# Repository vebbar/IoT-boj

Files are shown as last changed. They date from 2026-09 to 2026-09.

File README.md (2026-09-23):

# IoT-boj – temperaturmätning i insjö

> **Status: pågående projekt.** Detta repo speglar var projektet befinner sig just nu – hårdvaruval och krav är på plats, men kod, CAD och testning är inte klara ännu. Bidrag, förslag och issues är välkomna!

## Syfte

En solcellsdriven boj som mäter vattentemperatur på flera djup i en insjö och skickar mätdata trådlöst (LoRa) till en mottagare/basstation, som i sin tur vidarebefordrar datan till en NAS/server som publicerar den på en hemsida.

## Krav och funktion i korthet

- Mäter vattentemperatur på tre djup: **-0,3 m, -1 m, -2 m**, monterade på ett 2 m långt aluminiumrör under bojen
- Skickar temperatur + batteristatus **en gång i timmen**
- Placeras i allmänt vatten → ska vara **hyfsat billig** (risk för vandalisering/stöld)
- Ute **året runt i Stockholmsområdet** → måste tåla kyla
- Höljet **3D-printas**
- Strömförsörjs via **solcell (6 V/2 A) + 2x 18650-batteri**
- Kommunicerar via **LoRa (868 MHz)**, ca 100 m genom vegetation, till en mottagare
- Kommunikation sker alltid **boj → mottagare → server** (push), aldrig tvärtom

## Arkitektur

```
[Boj: Heltec Wireless Stick Lite V3    --LoRa 868MHz-->  [Mottagare: Waveshare
 (ESP32-S3+SX1262) + 3x DS18B20]                          ESP32-S3-POE-ETH + SX1276]
                                                                    |
                                                             push data
                                                                    v
                                                          [NAS/server → hemsida]
```

Mottagaren står fast vid sjön. Servern kan flytta med användaren till andra nät – därför initieras kommunikationen alltid från mottagaren mot servern, aldrig tvärtom.

## CAD

Höljet och de mekaniska delarna designas i Onshape: se [`cad/onshape-link.md`](cad/onshape-link.md) för länk och status.

## Hårdvara (sammanfattning)

**Boj**
- Heltec Wireless Stick Lite V3 (ESP32-S3 + inbyggt LoRa SX1262), 868 MHz
- 3x DS18B20 vattentäta temperatursensorer (0,3/1/2 m djup, på aluminiumrör)
- 2x 18650 Li-ion-celler med integrerad BMU
- Solcell 6 V/2 A + laddkrets CN3065 + buck-boost-converter
- INA219 för batteritelemetri

**Mottagare**
- Waveshare ESP32-S3-POE-ETH
- extern SX1276 LoRa-modul

**Regulatoriskt:** Sändare på 868 MHz, duty cycle max 1 % i bandet 868,0–868,6 MHz (~36 sek/timme) enligt PTS.

## Kända öppna frågor / risker

- **Is** är den största risken året runt i Stockholm – inte vind/vågor. Ett betongankare löser inte problemet med isflak. Att ta upp bojen inför islägget är den säkraste lösningen.
- Exakt placering (sjönamn/koordinater) publiceras medvetet **inte** här, för att minska risken för stöld/vandalisering.

## Licens

Detta projekt är licensierat under **MIT-licensen** – se [`LICENSE`](LICENSE). Det innebär i korthet att vem som helst får använda, kopiera, ändra och dela koden/materialet, även kommersiellt, så länge ursprungligt copyright-meddelande behålls. Programvaran ges utan garantier.

## Bidra

Detta är ett pågående hobbyprojekt. Öppna gärna en issue om du har frågor eller förslag.

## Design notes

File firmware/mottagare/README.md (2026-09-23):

# IoT-Boj LoRa Mottagare

LoRa-mottagare byggd på **Waveshare ESP32-S3-POE-ETH** med extern **SX1276** LoRa-modul. Tar emot textpaket från sändarbojen (Heltec Wireless Stick Lite V3) och skriver ut dem i Serial Monitor. Loggar också till den inbyggda TF-kortläsaren.

## Hårdvara

| Komponent | Modell |
|---|---|
| Mottagare | Waveshare ESP32-S3-POE-ETH |
| LoRa-modul | SX1276 (extern, via kablage) |
| (Valfritt) | TF-kort (inbyggt på mottagar-kortet) |

## Projektbeskrivning

Denna kod körs på en Waveshare ESP32-S3-POE-ETH och tar emot textpaket från sändarbojen via en extern SX1276 LoRa-modul. Varje mottaget paket skrivs ut i Serial Monitor tillsammans med RSSI och SNR, och loggas till den inbyggda TF-kortläsaren på kortet.

LoRa-inställningarna måste matcha sändaren: 868.0 MHz, bandbredd 125 kHz, spreading factor 7, coding rate 4/5 och sync word 0x3B. Payloaden innehåller temperaturer, sensorstatus och batterivärden från bojen och behandlas i nuläget som text.

## Viktiga pin-konflikter (ESP32-S3-POE-ETH)

ESP32-S3-POE-ETH har GPIO4/5/6/7 hårdkopplade till den inbyggda TF-kortplatsen, och GPIO9/10/11/12/13/14 hårdkopplade till det inbyggda W5500 Ethernet-chippet. De pinnarna kan INTE återanvändas för den externa LoRa-modulen. Därför körs LoRa och TF-kortet nu på två separata SPI-bussar med olika pinnar, istället för att dela en buss som i den gamla ESP32-C3-versionen.

GPIO0, GPIO3, GPIO45 och GPIO46 är strapping-pinnar och undviks medvetet.

NAS-stöd är förberett men avstängt. Senare kan `USE_NAS` och `sendToNas()` byggas ut med WiFi/HTTP (eller Ethernet via W5500) så att mottagna data skickas vidare till NAS.

> **OBS – innan detta pushas till en publik server:** `NAS_URL` är just nu en privat (lokal) IP-adress och skadar inte att dela. Om ni senare pekar mot en publik adress med autentisering, lägg autentiseringsuppgifter i en `.env`/hemlighetsfil (se `.gitignore` i repo-roten), aldrig direkt i koden.

## Pinout

### LoRa (extern SX1276, egen SPI-buss "loraSPI")
| Funktion | GPIO |
|---|---|
| SCK | 18 |
| MISO | 16 |
| MOSI | 17 |
| CS | 1 |
| RESET | 15 |
| DIO0 | 2 |

### TF-kort (inbyggt på kortet, egen SPI-buss "sdSPI", FASTA pinnar)
| Funktion | GPIO |
|---|---|
| SCK | 7 |
| MISO | 5 |
| MOSI | 6 |
| CS | 4 |

### Inbyggd LED (NeoPixel, GPIO 21)
| Status | LED |
|---|---|
| Lyssnar (ingen data) | Grön puls, mycket dim |
| Fel (CRC/error) | Röd, mycket dim |
| Paket mottaget | Blå blink (1 sekund) |

LED-styrning är standard inaktiverad (`USE_LED=0` i `main.cpp`). För att aktivera: sätt `#define USE_LED 1`

### Reserverat av Ethernet (W5500) — används inte av denna kod
GPIO9 (ETH_RST), GPIO10 (ETH_INT), GPIO11 (ETH_MOSI), GPIO12 (ETH_MISO), GPIO13 (ETH_CLK), GPIO14 (ETH_CS)

GND är gemensam för alla moduler.

## LoRa-inställningar (måste matcha sändare)

| Parameter | Värde |
|---|---|
| Frekvens | 868.0 MHz |
| Bandbredd | 125 kHz |
| Spreading factor | 7 |
| Coding rate | 4/5 |
| Sync word | 0x3B |

## Bygg och ladda upp

```bash
pio run -t upload
pio device monitor
```

Serial Monitor körs på 115200 baud (inställt i `platformio.ini`).

## Status

- `USE_SD` — SD-loggning aktiverad (sätt till 0 för felsökning utan TF-kort)
- `USE_NAS` — inaktivt (för framtida WiFi/Ethernet-integrering)

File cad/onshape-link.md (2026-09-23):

# CAD – Onshape

Käll-CAD för bojens hölje och mekaniska delar hålls i Onshape. Detta är den "levande" versionen – STEP/STL-filer i `step/` och `stl/` är exporterade ögonblicksbilder och kan ligga efter.

**Onshape-dokument:**
https://cad.onshape.com/documents/031defd88e958e1781d0b804/w/505ddeea769f05b2173c275a/e/bcfe48d20ba4c53c8e3ff33c

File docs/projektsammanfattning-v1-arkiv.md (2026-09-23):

# IoT-boj – Projektsammanfattning

*Sammanställd 2026-08-14 utifrån projektunderlag och diskussion.*

## Syfte
En temperaturboj som mäter vattentemperatur på flera djup och skickar data trådlöst till en basstation.

## Krav
- Mäter vattentemperatur på minst tre nivåer: **-0,2 m, -1 m, -2 m**
- Ev. lufttemperatur
- Placeras i **allmänt vatten** → ska vara **hyfsat billig** (risk för vandalisering/stöld)
- Ligger ute **året runt i Stockholm** → måste tåla kyla
- Höljet **3D-printas** (Bambu Lab P1S)
- Strömförsörjs via **solcell** som laddar batteri
- Kommunicerar via LoRa ca **100 m** till basstationen, genom vegetation ("foliage")
- Basstation: Raspberry Pi Zero W2 (finns redan), sitter kvar vid sjön hos föräldrarna
- Server flyttar med användaren till annat nät → kommunikation sker **Pi → server (push)**, aldrig tvärtom

## Fysiska mått (boj)
- Ungefär rund
- Omkrets ca **200 mm**
- Höjd/djup ca **150 mm**
- 3D-printas på Bambu Lab P1S

## Plats/miljö
- Insjö
- Vattendjup: **3 m**
- Vindutsatt läge

## Inköpslista – elektronik/IoT

### Styrenhet & radio
- ESP32 med inbyggt LoRa (SX1262), 868 MHz — motsvarande YourCee-modulen
- 3x DS18B20 vattentät temperatursensor (för -0,2, -1, -2 m djup)

### Kraftsystem
- 2–3x 18650 Li-ion-celler, gärna "protected"
- Batterihållare för 2–3 celler (parallellkoppling)
- Solar charge controller för 18650, t.ex. CN3065-baserad modul eller Adafruit/DFRobot Solar Lipo Charger
- Solpanel, ca 5–6V, 1–2W (extra marginal rekommenderas pga Stockholms vinter)
- Spänningsregulator (buck/boost till stabil 3,3V), om inte redan inbyggd
- Ev. INA219-modul för batterispänning/laddström (telemetri, systemhälsa)

### Övrig elektronik
- Vattentät SMA-genomföring (om extern antenn behövs)
- Vattentäta kabelgenomföringar (cable glands) för sensorkablar
- Reed switch (valfritt, för strömbrytning)

### Basstation (Raspberry Pi Zero W2 – finns redan)
- SX1276/78 LoRa-modul (868 MHz) — samma typ som SZFYDOSH-modulen
- SPI-kablage/pinheader till Pi:ns GPIO
- Antenn till LoRa-modulen (ingår ofta i kit)
- microSD-kort (tillräcklig storlek/klass för SQLite-loggning)

### Noteringar
- ESP32-C3 Super Mini används **inte** i slutgiltiga projektet
- Sändarfrekvens 868 MHz, duty cycle max 1% i bandet 868,0–868,6 MHz (~36 sek/timme) enligt PTS
- Basstationen sitter fast vid sjön; servern flyttar med användaren

## Förankring – beräkning och rekommendation

**Given flytkraft:** 5 kg

### Slutsats
En **25 kg säck betong**, gjuten till en klump, räcker med god marginal.

### Motivering
- Vindyta på bojen är liten (Ø~200 mm, ~150 mm höjd) → vindkraft ca 3–5 N även vid kraftig byvind
- Ström i insjö är svag (0,1–0,3 m/s) → liten kraft på nedsänkt del
- Betong väger ca 2000–2400 kg/m³ och tappar ~45–55% av sin vikt i vatten
- 25 kg betong i luft → ca 13–14 kg nedsänkt vikt → 2,5–3x marginal mot flytkraften, plus marginal mot vind/våg/ström

### Praktiska rekommendationer
- Gjut betongen i en hink/spann, gjut in en ögla/bult för infästning
- Använd en kort kätting (0,5–1 m) närmast klumpen, sedan lina upp till bojen — ger horisontellt drag och minskar risk att ankaret lyfts
- **Scope (linlängd):** sikta på 6–9 m totalt (2–3x vattendjupet på 3 m)

### ⚠️ Viktig varning – is
Den verkliga risken året runt i Stockholm är **is**, inte vind/vågor. Ett rörligt isflak kan ge krafter som vida överstiger vad ett betongankare klarar av, och kan dra ner eller krossa bojen. Vanliga lösningar:
- Ta upp bojen inför islägg, **eller**
- Acceptera risk för förlust/skada under vintern

Betongankaret löser inte is-problematiken.

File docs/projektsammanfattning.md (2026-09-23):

# IoT-boj – Projektsammanfattning (uppdaterad)

*Senast uppdaterad 2026-09-23.*

> Denna fil ersätter tidigare version. Den äldre versionen (med djupen -0,2/-1/-2 m) finns kvar i [`projektsammanfattning-v1-arkiv.md`](projektsammanfattning-v1-arkiv.md) för historik, men uppgifterna nedan är de aktuella.

## Syfte

Ett projekt bestående av en boj som mäter vattentemperaturen i en insjö i Stockholmsområdet, samt en mottagare/basstation som vidarebefordrar datan till en NAS/server som i sin tur publicerar den på en hemsida.

## Funktion

- Bojen har tre temperatursonder på tre djup: **0,3 m, 1 m, 2 m**
- Sonderna sitter monterade på ett **2 m långt aluminiumrör** under bojen
- Bojen skickar temperaturdata **en gång i timmen**, tillsammans med batteristatus
- Data tas emot av en mottagare ca **100 m** bort
- Mottagaren skickar vidare datan till en **NAS/server**, som publicerar den på en **hemsida**

## Hårdvara – Boj

- Styrenhet/radio: **Heltec Wireless Stick Lite (V3)** – ESP32-S3 + SX1262 LoRa-nod (Meshtastic- och LoRaWAN-kompatibel)
- 2x 18650-batterier med integrerad BMU (batterihanteringskrets)
- 3x DS18B20 vattentäta temperatursensorer
- Solcell, 6 V / 2 A
- Laddkrets: CN3065
- Buck-boost-converter (spänningsreglering)
- INA219 för batteritelemetri (spänning/ström)

## Hårdvara – Mottagare

- **Waveshare ESP32-S3-POE-ETH**
- Extern **SX1276** LoRa-modul

## Krav (bakgrund, se även syfte-och-krav.md)

- Placeras i allmänt vatten → ska vara hyfsat billig (risk för vandalisering/stöld)
- Ute året runt i Stockholm → måste tåla kyla
- Höljet 3D-printas
- Solcellsladdat batteri
- LoRa 868 MHz, ca 100 m genom vegetation
- Kommunikation sker boj/mottagare → server (push), aldrig tvärtom

## Förankring – beräkning och rekommendation

**Given flytkraft:** 5 kg

### Slutsats
En **25 kg säck betong**, gjuten till en klump, räcker med god marginal.

### Motivering
- Vindyta på bojen är liten → vindkraft ca 3–5 N även vid kraftig byvind
- Ström i insjö är svag (0,1–0,3 m/s) → liten kraft på nedsänkt del
- Betong väger ca 2000–2400 kg/m³ och tappar ~45–55 % av sin vikt i vatten
- 25 kg betong i luft → ca 13–14 kg nedsänkt vikt → 2,5–3x marginal mot flytkraften

### Praktiska rekommendationer
- Gjut betongen i en hink/spann, gjut in en ögla/bult för infästning
- Kort kätting (0,5–1 m) närmast klumpen, sedan lina upp till bojen
- **Scope (linlängd):** sikta på 6–9 m totalt (2–3x vattendjupet på 3 m)

### ⚠️ Viktig varning – is
Den verkliga risken året runt i Stockholm är **is**, inte vind/vågor. Ett rörligt isflak kan ge krafter som vida överstiger vad ett betongankare klarar av. Vanliga lösningar:
- Ta upp bojen inför islägg, **eller**
- Acceptera risk för förlust/skada under vintern

Betongankaret löser inte is-problematiken.

## Noteringar

- ESP32-C3 Super Mini används **inte** i det slutgiltiga projektet
- Sändarfrekvens 868 MHz, duty cycle max 1 % i bandet 868,0–868,6 MHz (~36 sek/timme) enligt PTS
- Basstationen sitter fast vid sjön (hos föräldrarna); servern flyttar med användaren till andra nät

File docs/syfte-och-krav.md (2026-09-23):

Bojen ska mäta vattentemperaturen på minst tre nivåer -0,2, -1 och -2m. Och eventuellt lufttemperatur. Bojen kommer befinna sig i Allmänt vatten så ska vara hyfsat billigt då den lätt kan bli vandaliserad eller stulen. Bojen kommer vara ute året runt (Stockholm) så behöver tåla vis kyla. Bojen kommer att 3d printas. För att bojen ska fungera komer den behöva en solceller för att ladda upp batteriet/er. Bojen kommer befinna sig ca 100m från basstationen genom foliage.

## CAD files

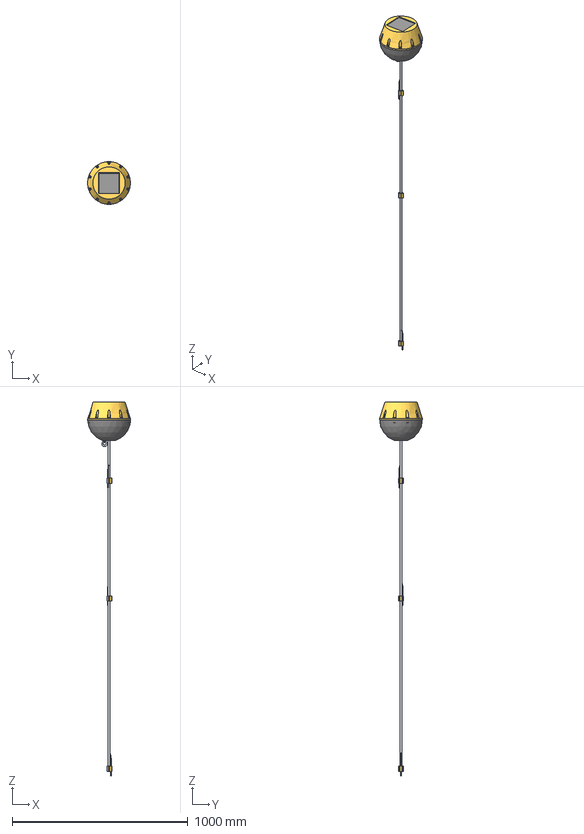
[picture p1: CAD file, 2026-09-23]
cad/IoT-boj Assembly.step
243.8 x 243.8 x 2128.9 mm
fyrkants mutter x 10
Bult x 10
boj_top
boj_base
solcell
bricka
ögla
mutter
DS18B20 clip x 3
DS18B20 x 3
aluminium stång
Solar Charger v1.0
Heltec esp32 LoRa
TPS63020 Buck Boost
Kopplingsdosa
Kopplingsdosa_lock
Kopplingsdosa pakning

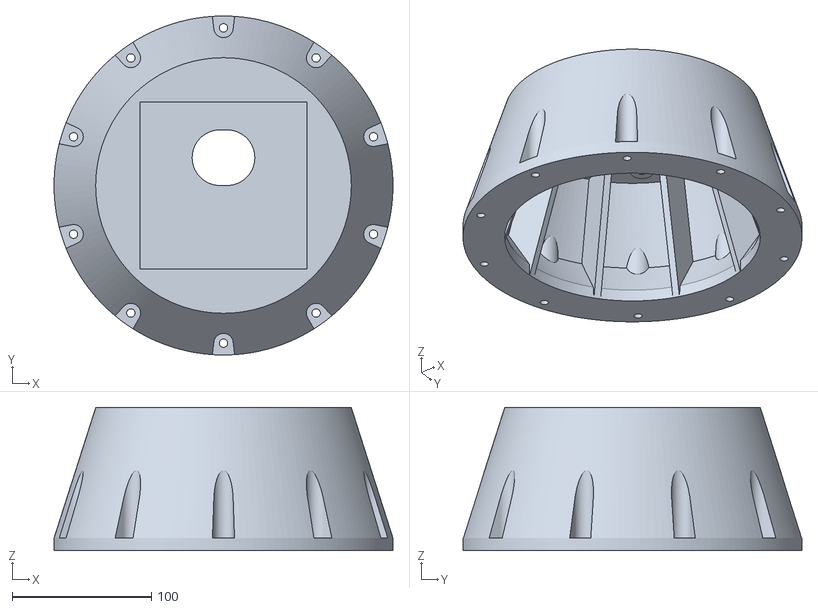
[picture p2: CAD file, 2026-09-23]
cad/Boj_Top.stl
243.8 x 243.8 x 103.0

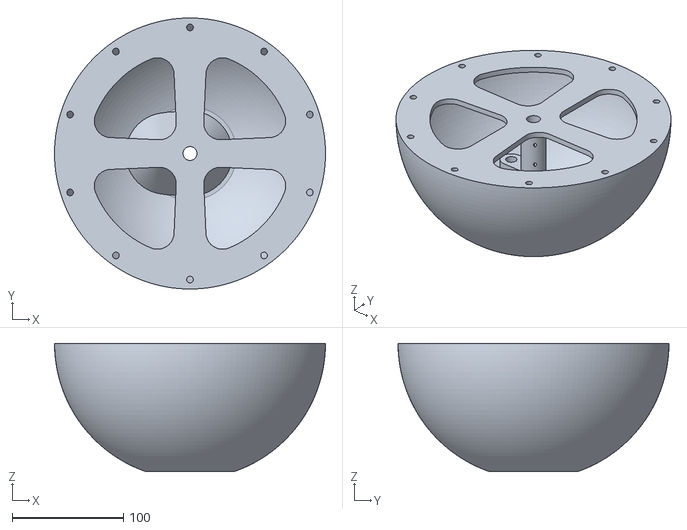
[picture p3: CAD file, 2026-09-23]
cad/Boj_Base.stl
243.8 x 243.8 x 115.2

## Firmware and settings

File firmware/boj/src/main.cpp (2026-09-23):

#define HELTEC_WIRELESS_STICK_LITE   // måste stå FÖRE include-raden nedan
#define HELTEC_NO_DISPLAY            // Stick Lite saknar skärm, slipper onödig init
#include <heltec_unofficial.h>       // skapar en färdig 'radio'-instans med rätt pinnar för just detta kort

#include <Arduino.h>
#include <OneWire.h>
#include <DallasTemperature.h>
#include <Wire.h>
#include <Adafruit_INA219.h>

// Data-sladd för DS18B20 sensorer på GPIO 15
const int ONE_WIRE_PIN = 15;
//SDA från INA219 på GPIO 2
const int SDA_PIN = 2;
//SCL från INA219 på GPIO 7
const int SCL_PIN = 7;

Adafruit_INA219 ina219;
OneWire oneWireBus(ONE_WIRE_PIN);
DallasTemperature sensors(&oneWireBus);

const int NUM_SENSORS = 3;

// Sensoradresser för DS18B20
// Sensor 1 (0.3m): 28CAFDC3000000B5
// Sensor 2 (1.0m): 28AE33C4000000AC
// Sensor 3 (2.0m): 2833C9C3000000CA
DeviceAddress sensorAddresses[NUM_SENSORS] = {
  {0x28, 0xCA, 0xFD, 0xC3, 0x00, 0x00, 0x00, 0xB5},
  {0x28, 0xAE, 0x33, 0xC4, 0x00, 0x00, 0x00, 0xAC},
  {0x28, 0x33, 0xC9, 0xC3, 0x00, 0x00, 0x00, 0xCA}
};

// Etiketter för utskrift, en per sensor/djup
const char* depthLabels[NUM_SENSORS] = {"0.3m", "1.0m", "2.0m"};

// Senaste kända bra värde per sensor (används om en mätning misslyckas) sparat i RTC minne
RTC_DATA_ATTR float lastGoodTemp[NUM_SENSORS] = {0.0, 0.0, 0.0};

bool ina219Available = false;  // global variabel, börjar som "inte tillgänglig"

// OBS: 'radio' (SX1262) skapas automatiskt av heltec_unofficial.h ovan,
// med korrekta pinnar för Wireless Stick Lite V3 - ingen egen Module()-instans behövs.

struct TemperatureResult {
  float averageTemperature;
  bool isSuccessful;
  float rawTemperature;
};

void getSafeTemperatures(TemperatureResult results[], int samples);

void setup() {
  heltec_setup();  // Initierar Serial, SPI (hspi->begin) och display (om aktiv)
  Serial.println("CHECKPOINT 1: heltec_setup() klar");

  heltec_ve(true); // Slår på Vext-strömskenan -- annars är externa sensorer (t.ex. INA219) strömlösa
  Serial.println("CHECKPOINT 2: heltec_ve(true) klar");

  delay(300);      // ge Vext-skenan gott om tid att stabiliseras innan sensorer pratas med
  Serial.println("CHECKPOINT 3: delay(300) klar");

  unsigned long serialWaitStart = millis(); //väntar på usb kontakt i 3 sekunder
  while (!Serial && millis() - serialWaitStart < 3000) {
    delay(10);
  }
  Serial.println("CHECKPOINT 4: serial-vantan klar");

  sensors.begin();
  Serial.println("CHECKPOINT 5: sensors.begin() klar");

  int deviceCount = sensors.getDeviceCount();
  Serial.println("CHECKPOINT 6: sensors.getDeviceCount() klar");
  Serial.print("DS18B20: hittade ");
  Serial.print(deviceCount);
  Serial.println(" sensorer.");
  if (deviceCount < NUM_SENSORS) {
    Serial.println("VARNING: färre sensorer hittades än förväntat!");
  }

  Wire.begin(SDA_PIN, SCL_PIN);
  Serial.println("CHECKPOINT 7: Wire.begin() klar");

  Wire.setClock(100000);  // konservativ I2C-hastighet (100kHz) för tillförlitligare läsningar
  Serial.println("CHECKPOINT 8: Wire.setClock() klar");

  // "Väck" I2C-bussen genom att snabbt pinga alla möjliga adresser en gång.
  // Detta visade sig lösa ett problem där INA219 inte svarade tillförlitligt
  // direkt efter Vext-strömpåslag - troligen på grund av hur ESP32:ans
  // I2C-drivrutin återhämtar bussen efter flera transaktioner (inklusive NACK:ar).
  for (byte addr = 1; addr < 127; addr++) {
    Wire.beginTransmission(addr);
    Wire.endTransmission();
  }
  Serial.println("CHECKPOINT 9: I2C-bus-scan klar");

  bool ina219Found = false;
  for (int attempt = 1; attempt <= 5 && !ina219Found; attempt++) {
    if (ina219.begin()) {
      ina219Found = true;
    } else {
      delay(50);
    }
  }
  Serial.println("CHECKPOINT 10: ina219.begin()-forsok klara");

  if (!ina219Found) {
    Serial.println("Kunde inte hitta INA219! Fortsätter utan batterimätning denna cykel.");
    // ina219Available förblir false, ingen while(1) här
  } else {
    ina219Available = true;
    Serial.println("INA219 hittad, startar mätning...");
  }

  // Initiera LoRa (SX1262) - 'radio' kommer från heltec_unofficial.h
  Serial.println("Initierar LoRa...");
  int state = radio.begin(868.0, 125.0, 7, 5, 0x3B, 12);
  Serial.println("CHECKPOINT 11: radio.begin() klar");
  if (state != RADIOLIB_ERR_NONE) {
    Serial.println("LoRa init misslyckades: " + String(state));
  } else {
    Serial.println("LoRa init OK.");
  }

  // Mät alla sensorer
  TemperatureResult results[NUM_SENSORS];
  getSafeTemperatures(results, 3);
  Serial.println("CHECKPOINT 12: getSafeTemperatures() klar");

  // Bygg payload (textformat)
  String payload = "";
  for (int i = 0; i < NUM_SENSORS; i++) {
    if (results[i].isSuccessful) {
      lastGoodTemp[i] = results[i].averageTemperature;
    }

    payload += "T_";
    payload += depthLabels[i];
    payload += ":";
    payload += String(lastGoodTemp[i], 1);
    payload += ",S";
    payload += String(i);
    payload += ":";
    payload += results[i].isSuccessful ? "1" : "0";

    if (i < NUM_SENSORS - 1) {
      payload += ",";
    }
  }

  if (ina219Available) {
    float voltage = ina219.getBusVoltage_V() + (ina219.getShuntVoltage_mV() / 1000);
    float current = ina219.getCurrent_mA();
    float power = ina219.getPower_mW();
    payload += ",Vbat:";
    payload += String(voltage, 2);
    payload += "V,I:";
    payload += String(current, 0);
    payload += "mA,P:";
    payload += String(power, 0);
    payload += "mW";
  } else {
    payload += ",Vbat:OFFLINE";
  }
  Serial.println("CHECKPOINT 13: payload byggd");

  // Skriv till Serial för felsökning
  Serial.println("Payload: " + payload);

  // Sänd via LoRa
  if (state == RADIOLIB_ERR_NONE) {
    Serial.println("Sänder via LoRa...");
    int txState = radio.transmit(payload);
    Serial.println("CHECKPOINT 14: radio.transmit() klar");
    if (txState != RADIOLIB_ERR_NONE) {
      Serial.println("LoRa sändning misslyckades: " + String(txState));
    } else {
      Serial.println("LoRa sändning klar.");
    }
  }

  // Gå i deep sleep i 1 timme
  Serial.println("Går i deep sleep i 1 timme...");
  heltec_ve(false);  // Stäng av Vext -- annars drar pull-up-resistorn ström i onödan under hela sömnen
  delay(100); // ge tid för Serial-att avsluta
  heltec_deep_sleep(3600);  // Sätter radio i sleep, sätter timer wakeup + esp_deep_sleep_start()
}

void loop() {
  // Tom - inget händer här efter deep sleep-setup
}

/**
 * @brief Mäter temperaturen på alla sensorer samtidigt, flera gånger,
 *        och beräknar medelvärdet av de godkända mätningarna per sensor.
 *
 * @param results Array (storlek NUM_SENSORS) dit resultaten skrivs.
 * @param samples Antal mätomgångar som ska göras.
 */
void getSafeTemperatures(TemperatureResult results[], int samples) {
  float sumOfGoodTemps[NUM_SENSORS] = {0};
  int countOfGoodTemps[NUM_SENSORS] = {0};
  float lastObservedTemp[NUM_SENSORS] = {0};

  for (int i = 0; i < samples; i++) {
    sensors.requestTemperatures();  // EN broadcast per sample, alla sensorer samtidigt

    for (int s = 0; s < NUM_SENSORS; s++) {
      float currentTemp = sensors.getTempC(sensorAddresses[s]);
      lastObservedTemp[s] = currentTemp;

      // Kontrollera om värdet är inom det godkända intervallet
      if (currentTemp > -30.0 && currentTemp < 40.0) {
        sumOfGoodTemps[s] += currentTemp;
        countOfGoodTemps[s]++;
      }
    }
  }

  for (int s = 0; s < NUM_SENSORS; s++) {
    if (countOfGoodTemps[s] > 0) {
      results[s].averageTemperature = sumOfGoodTemps[s] / countOfGoodTemps[s];
      results[s].isSuccessful = true;
      results[s].rawTemperature = lastObservedTemp[s];
    } else {
      results[s].averageTemperature = 0.0;
      results[s].isSuccessful = false;
      results[s].rawTemperature = lastObservedTemp[s];
    }
  }
}

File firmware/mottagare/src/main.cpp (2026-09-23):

// Se README.md för full dokumentation av pinout, LoRa-inställningar och LED-beteende.

#include <Arduino.h>
#include <SPI.h>
#include <RadioLib.h>

// TF-kortet sitter inbyggt på kortet, så SD-loggning är påslaget som standard.
// Sätt till 0 om du vill köra utan SD-loggning (t.ex. för felsökning).
#define USE_SD 1
// Forberedelse for framtida NAS-integration (t.ex. via Ethernet/W5500).
constexpr bool USE_NAS = false;
constexpr char NAS_URL[] = "http://192.168.1.100:8086/api/v1/temps";

// ---------- LoRa (extern SX1276-modul, egen SPI-buss) ----------
// OBS! GPIO21 är enligt schemat (R15, 0R) hårdkopplad till den inbyggda WS2812
// RGB-lysdioden. LORA_CS flyttad hit ifrån för att slippa krocka med den.
constexpr int LORA_SCK   = 18;
constexpr int LORA_MISO  = 16;
constexpr int LORA_MOSI  = 17;
constexpr int LORA_CS    = 1;
constexpr int LORA_RESET = 15;
constexpr int LORA_DIO0  = 2;

constexpr float LORA_FREQUENCY = 868.0;
constexpr float LORA_BANDWIDTH = 125.0;
constexpr uint8_t LORA_SPREADING_FACTOR = 7;
constexpr uint8_t LORA_CODING_RATE = 5;
constexpr uint8_t LORA_SYNC_WORD = 0x3B;
constexpr int8_t LORA_POWER = 12;

// ---------- TF-kort (inbyggt, fasta pinnar - får INTE ändras) ----------
constexpr int SD_SCK  = 7;
constexpr int SD_MISO = 5;
constexpr int SD_MOSI = 6;
constexpr int SD_CS   = 4;

// Två separata SPI-bussar så att LoRa och TF-kortet inte krockar.
SPIClass loraSPI(FSPI);
#if USE_SD
SPIClass sdSPI(HSPI);
#endif

Module loraModule(LORA_CS, LORA_DIO0, LORA_RESET, RADIOLIB_NC, loraSPI);
SX1276 radio(&loraModule);

unsigned long lastHeartbeat = 0;
constexpr unsigned long HEARTBEAT_INTERVAL = 30000; // 30 sekunder

bool sdReady = false;

// ---------- LED (inbyggd WS2812 NeoPixel, GPIO 21 på Waveshare ESP32-S3-POE-ETH) ----------
// GPIO21 är nu fri för LED eftersom LORA_CS flyttades till GPIO1 ovan.
#define USE_LED 1
constexpr int LED_PIN = 21;
constexpr int LED_DIM = 5;                    // Mycket svag hellighet (0-255)
constexpr int LED_BLUE_DURATION = 1000;       // 1 sekund
constexpr int LED_BLINK_MS = 200;             // Blink-intervall

#if USE_LED
unsigned long ledBlueStart = 0;
bool ledBlueActive = false;
#endif

#if USE_SD
#include <SD.h>
#endif

void logToSd(const String& payload) {
#if USE_SD
  if (!sdReady) {
    return;
  }

  File logFile = SD.open("/temperature_log.txt", FILE_APPEND, true);
  if (!logFile) {
    Serial.println("SD: kunde inte oppna temperature_log.txt");
    return;
  }

  logFile.println(payload);
  logFile.close();
#endif
}

void sendToNas(const String& payload) {
  if (USE_NAS) {
    // NAS skickas inte annu. Behall payloaden har for framtida WiFi/HTTP-stod.
    Serial.print("NAS ej implementerad, URL: ");
    Serial.println(NAS_URL);
    Serial.println(payload);
  }
}

void setup() {
  Serial.begin(115200);
  delay(2000);  // Längre delay för USB CDC att komma igång

  Serial.println();
  Serial.println("=== IoT-Boj LoRa-mottagare BOOT (ESP32-S3-POE-ETH) ===");
  Serial.println("LoRa-SPI: SCK=GPIO18 MISO=GPIO16 MOSI=GPIO17");
  Serial.println("LoRa: CS=GPIO1 RESET=GPIO15 DIO0=GPIO2");
  Serial.println("TF-kort (inbyggt): SCK=GPIO7 MISO=GPIO5 MOSI=GPIO6 CS=GPIO4");

  loraSPI.begin(LORA_SCK, LORA_MISO, LORA_MOSI, LORA_CS);

#if USE_SD
  sdSPI.begin(SD_SCK, SD_MISO, SD_MOSI, SD_CS);
  if (!SD.begin(SD_CS, sdSPI)) {
    Serial.println("SD: initiering misslyckades (kontrollera att TF-kort sitter i), fortsatter utan SD");
    sdReady = false;
  } else {
    Serial.println("SD: initiering OK, loggar till /temperature_log.txt");
    sdReady = true;
  }
#else
  Serial.println("SD: avstangd i kod (USE_SD=0), LoRa fungerar utan SD-kort");
#endif

  Serial.println("Initierar LoRa...");
  int state = radio.begin(
      LORA_FREQUENCY,
      LORA_BANDWIDTH,
      LORA_SPREADING_FACTOR,
      LORA_CODING_RATE,
      LORA_SYNC_WORD,
      LORA_POWER,
      8);

  if (state != RADIOLIB_ERR_NONE) {
    Serial.print("LoRa init misslyckades, felkod: ");
    Serial.println(state);
    Serial.println("Kontrollera strom, GND, SPI-pinnar och SX1276-kopplingen.");
    while (true) {
      delay(1000);
    }
  }

  Serial.println("LoRa init OK");
  Serial.println("Vantar pa paket...");

#if USE_LED
  neopixelWrite(LED_PIN, 0, 0, 0);  // Stäng av inbyggd LED direkt
#endif
}

void loop() {
  unsigned long now = millis();

#if USE_LED
  // LED: blå blink (1 sekund) efter mottaget paket
  if (ledBlueActive && now - ledBlueStart < LED_BLUE_DURATION) {
    neopixelWrite(LED_PIN, 0, 0, ((now / LED_BLINK_MS) % 2) ? LED_DIM : 0);
  } else if (ledBlueActive && now - ledBlueStart >= LED_BLUE_DURATION) {
    ledBlueActive = false;
    neopixelWrite(LED_PIN, 0, 0, 0);
  }

  // LED: grön puls när ingen blå blink pågår
  if (!ledBlueActive) {
    unsigned long t = now % 2000;
    uint8_t brightness = (t < 1000) ? (t * LED_DIM / 1000) : ((2000 - t) * LED_DIM / 1000);
    neopixelWrite(LED_PIN, 0, brightness, 0);
  }
#endif

  if (now - lastHeartbeat >= HEARTBEAT_INTERVAL) {
    lastHeartbeat = now;
    Serial.print("[HB] ");
    Serial.print(now / 1000);
    Serial.print("s - lyssnar på 868.0 MHz (SF7, BW125, CR4/5, Sync 0x12) - SD: ");
    Serial.println(sdReady ? "OK" : "AV");
  }

  String payload;
  int state = radio.receive(payload);

  if (state == RADIOLIB_ERR_NONE) {
#if USE_LED
    ledBlueActive = true;
    ledBlueStart = millis();
    neopixelWrite(LED_PIN, 0, 0, LED_DIM);
#endif

    Serial.println();
    Serial.println("--- LoRa-paket mottaget ---");
    Serial.print("RSSI: ");
    Serial.print(radio.getRSSI());
    Serial.println(" dBm");
    Serial.print("SNR: ");
    Serial.print(radio.getSNR());
    Serial.println(" dB");
    Serial.print("Payload: ");
    Serial.println(payload);

    logToSd(payload);
    sendToNas(payload);
    Serial.println("---------------------------");
  } else if (state == RADIOLIB_ERR_CRC_MISMATCH) {
    Serial.println("LoRa-paket avvisat: CRC-fel");
#if USE_LED
    if (!ledBlueActive) neopixelWrite(LED_PIN, LED_DIM, 0, 0);
#endif
  } else if (state == RADIOLIB_ERR_RX_TIMEOUT) {
    delay(100);
  } else {
    Serial.print("LoRa mottagningsfel: ");
    Serial.println(state);
#if USE_LED
    if (!ledBlueActive) neopixelWrite(LED_PIN, LED_DIM, 0, 0);
#endif
    delay(100);
  }
}

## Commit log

2026-09-23 Revise temperature depths and communication details
    Updated temperature measurement depths and communication flow in the README.
2026-09-23 Revise README content and add CAD section
    Updated the README to reflect changes in project structure and added CAD section.
